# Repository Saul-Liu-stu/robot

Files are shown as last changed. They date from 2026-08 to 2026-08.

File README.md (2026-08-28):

# 轮腿混合四足机器人 robot_four_leg

基于 STM32H743 的轮腿混合机器人项目：四足步态 + 轮式移动双运动模式，含 IMU 姿态自稳、主动越障（原地抬腿/台阶辅助）与云台视觉，配套 Qt Android 蓝牙控制端 APP 与完整工程文档。

## 硬件平台

| 模块 | 型号 / 数量 | 接口 |
|---|---|---|
| 主控 | STM32H743ZIT6 (LQFP144) @ 480MHz | — |
| 舵机 | 12× 270°（4 腿 × 外展/大腿/小腿） | TIM2/3/4/12 PWM 50Hz |
| 轮电机 | 4× MG513 + TB6612 驱动（腿末端驱动轮） | TIM1/16/17 PWM |
| 编码器 | 4× GMR（与轮电机配套，轮速测量） | EXTI 双沿计数 |
| IMU | WT9011G4K | USART2 |
| 蓝牙 | HC-05（经典蓝牙 SPP） | USART3 |
| 云台 | 2× 180° 舵机 + 图传模块 | PWM |

完整引脚分配见 `docs/硬件/控制板引脚分配表.md`。

## 核心功能

- **轮腿双模**：平地轮式高效移动（最高约 1.7 m/s），崎岖地形对角步态（TROT）行走
- **足端轨迹规划 + 3D IK**：步态机以足端位置为控制目标，三关节解析逆解驱动 12 路舵机
- **姿态自稳**：IMU 反馈四腿 z 差动补偿，倾斜地面机身保持水平（Z 标定 + 开关控制）
- **主动越障**：原地抬腿（W，对角支撑+重心补偿）、台阶辅助抬升（N，双腿直抬+轮滚协同）
- **云台视觉**：二自由度云台 + 图传回传，APP 端颜色/运动检测
- **在线调参**：ASCII 蓝牙协议全指令文档化，运动参数在线可调

## 项目结构

```
robot_four_leg/
├── Core/           # STM32 用户层（main、命令协议解析、模式状态机）
├── Hardware/       # 行为/硬件层（步态 walk_gait、逆解 leg_ik、姿态控制 attitude_control、抬腿机动、轮式控制、云台、驱动）
├── Drivers/        # CMSIS + STM32H7xx HAL 库
├── QT_APP/         # Qt Android 蓝牙控制端 APP（UI/蓝牙传输/协议解析三层）
├── tools/          # Python 步态仿真与调参工具（IK 校验、行程余量、站起路径检查）
├── 3D结构文件/     # 机身与腿部 3D 打印模型（STL/STEP）
├── docs/           # 工程文档（协议、功能总览、测试清单、硬件资料、需求文档）
└── robot_four_leg.ioc   # CubeMX 工程配置
```

## 文档

- 蓝牙通信协议：`docs/协议/蓝牙通信协议.md`
- 功能总览：`docs/功能总览.md`
- 功能测试清单：`docs/功能测试清单.md`
- IMU 姿态自稳实现说明：`docs/IMU姿态控制方案.md`
- 需求文档：`docs/需求文档.md`
- 竞赛提交材料（开发日志、需求文档正式版等）：见材料包

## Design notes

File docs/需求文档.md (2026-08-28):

# 灵犬先锋轮腿机器人需求文档

| | |
|---|---|
| 项目名称 | 灵犬先锋——面向野外环境的探测与救援轮腿机器人 |
| 文档版本 | V1.0 |
| 编制日期 | 2026 年 8 月 10 日 |
| 编制人 | 项目团队 |

## 1. 项目背景

野外探测与救援任务中，废墟、山地、草地/土坡等复杂环境对移动平台提出苛刻要求：传统轮式平台通过性不足，纯四足平台平地效率低、控制复杂。本项目在电赛 QuadArm 原型基础上迭代，定位为**低成本的轮腿混合移动平台**——平地轮式高效移动，崎岖地形步态行走，并以 IMU 姿态自稳与主动越障能力支撑野外环境作业，为探测与救援类应用提供平台基础。

## 2. 目标与范围

- **目标**：以不超过 2000 元整机成本，实现轮腿双模移动、姿态自稳、主动越障与云台视觉四项核心能力，完成样机验证；
- **范围**：机器人本体（结构、硬件、固件）+ QT 蓝牙控制端（遥控 + 视觉检测）；
- **不包含**：自主导航、机械臂操作、远距通信（预留迭代空间）。

## 3. 功能需求

| 编号 | 需求描述 | 优先级 |
|---|---|---|
| FR-1 | 轮式移动：前进、后退、左转、右转、原地自转，四轮独立驱动 | 高 |
| FR-2 | 步态移动：对角步态（TROT），步长、步高、站高、站姿宽度参数化可调 | 高 |
| FR-3 | 站姿切换：高/低站姿切换与前倾修正 | 高 |
| FR-4 | 站起/趴下：站起机动（趴姿→站姿路径规划） | 中 |
| FR-5 | 姿态自稳：IMU 反馈四腿 z 差动补偿，倾斜地面机体保持水平（Z 标定 + 开关控制） | 高 |
| FR-6 | 主动越障：原地抬腿（对角支撑）；台阶辅助抬升（双腿同步直抬，与轮滚协同） | 高 |
| FR-7 | 云台与图传：二自由度云台指向控制，摄像头画面图传回传 | 中 |
| FR-8 | 上位机视觉：QT 端颜色检测与运动检测 | 中 |
| FR-9 | 遥控：按键遥控页（四向控制、速度档、站姿宽度调节），蓝牙串口协议全指令文档化 | 高 |
| FR-10 | 在线调参：全部运动参数支持在线修改，无需重新烧录 | 高 |

## 4. 性能需求

| 编号 | 指标 | 目标值 |
|---|---|---|
| PR-1 | 站高 | 210~280mm 在线可调（常用站姿 230mm） |
| PR-2 | 主动抬腿高度 | ≥50mm |
| PR-3 | 台阶通过 | 6~7cm |
| PR-4 | 坡面通过 | ≥10° |
| PR-5 | 轮式速度 | ≥1.5 m/s（轮毂直径 11cm，电机最高 300rpm） |
| PR-6 | 续航 | ≥1h（3S 2550mAh ×2） |
| PR-7 | 整机重量 | ≤1.5kg |
| PR-8 | 姿态自稳 | 死区 0.7°，稳态残差收敛（积分项消除） |
| PR-9 | 姿态反馈 | IMU 10Hz（俯仰/横滚） |
| PR-10 | 整机成本 | ≤2000 元 |

## 5. 可靠性需求

| 编号 | 需求描述 |
|---|---|
| RR-1 | IWDG 独立看门狗：异常卡死自动复位 |
| RR-2 | 舵机行程余量校验：所有姿态执行前校验行程可行性 |
| RR-3 | 姿态标定：各站姿 IMU 零偏分槽存储，上电可标定（Z 命令） |
| RR-4 | 抬腿高度受舵机行程约束保护（≤50mm） |

## 6. 设计约束

- 硬件平台：STM32H743 主控 + 12×270° 舵机 + 4×MG513 轮电机（TB6612）+ WT9011G4K IMU + 4×GMR 编码器 + 2×180° 云台舵机 + HC-05 蓝牙；
- 团队规模：3 人；开发周期：2026 年 8 月（约一个月集中开发）；
- 成本上限：2000 元；
- 通信：蓝牙串口（近距离遥控，远距通信为后续迭代方向）。

## 7. 验收对照

需求验收以《功能测试清单》逐项回归为准（姿态控制 / 步态 / 越障 / 遥控四类场景），全部核心场景通过即视为需求达成，遗留低优先级改进项记录于开发日志问题追踪表。

## 8. 需求变更记录

| 版本 | 日期 | 变更内容 |
|---|---|---|
| V1.0 | 2026 年 8 月 10 日 | 初版：功能迭代开始前需求梳理定稿 |

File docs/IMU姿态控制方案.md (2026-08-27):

# 四足轮腿机器人 IMU 姿态自稳实现说明

> 适用硬件：12 路舵机 + 4 路轮电机，IMU 为 WT9011G4K（UART 10Hz 主动上报）。
> 本文档描述**已实现的站立自稳**（attitude_control.c/h），非设计稿。

---

## 1. 功能概述

站立自稳：机器人在倾斜地面站立时，通过 IMU 姿态反馈，自动调节四腿足端高度（z 方向差动补偿），使机身保持水平。支持：

- 手动开关（`L:1`/`L:0` 绝对值命令，`L:` 裸命令切换）
- Z 标定（各姿态零偏分槽存储）
- 站立/原地抬腿（W 模式）自动激活
- 无倾斜轮式驱动（V 模式 1）自动跟随

## 2. 数据流

```
WT9011G4K (10Hz 上报)
   └─ imu.c 解析 pitch/roll
        └─ AttCtrl_CalibTick()   标定状态机 (5ms, 采样 2s 均值存零偏)
             └─ AttCtrl_LevelUpdate()   自稳解算 (50/100ms)
                  ├─ 低通滤波去抖
                  ├─ 软死区抑制微晃
                  ├─ 比例 + 积分 (消重心偏载常驻残差)
                  └─ 四腿 z 差动输出 (按站高动态限幅)
```

## 3. Z 标定与姿态分槽

不同站姿的 IMU 零偏不同，按姿态分槽存储（5 槽）：

| 槽 | 姿态 | 说明 |
|---|---|---|
| 0 | H（前后不反转，高） | 上电默认低趴并入此槽 |
| 1 | K（前反后不反，高） | |
| 2 | L（前反后不反，低） | |
| 3 | M（前不反后反，低） | |
| 4 | P（前不反后反，高） | |

- `Z` 命令：开始标定（放平地保持静止 2 秒）
- 标定完成后该姿态槽允许开启自稳（未标定姿态 `L:1` 返回错误）

## 4. 控制律

对相对零偏的俯仰/横滚角做处理：

```
flat_p = pitch - offset[pose]      (前倾为正)
flat_r = roll  - roffset[pose]     (右倾为正)

① 低通:  s_lp += alpha * (flat - s_lp)     alpha=0.25 @10Hz ≈ 0.35s 时间常数
② 软死区: |angle| < 0.7° → 0 (无阶跃软过渡)
③ 积分:  s_i += KI * dp, 钳位 pitch ±3° / roll ±6° (仅正常模式)
④ 输出:  pc = (dp + s_i) * rad * 190 (前后髋半距)
         rc = (dr + s_i) * rad * 90  (左右髋半宽)
         dz[FL]=pc-rc  dz[FR]=pc+rc  dz[RL]=-pc-rc  dz[RR]=-pc+rc
⑤ 限幅:  |dz| ≤ 304.6 - stand_h  (按站高动态算伸腿余量)
```

- **软死区**：±0.7° 内不响应（1° 偏粗、0.5° 过敏感，实测折中 0.7°）
- **积分项**：消除重心偏载的常驻残差（纯比例有稳态下垂），抗饱和钳位防发散
- **符号约定**：前倾→前腿伸/后腿收；右倾→右腿伸/左腿收

## 5. 激活条件（主循环判定）

| 场景 | 条件 |
|---|---|
| 站立 | `L:1` 已开 且 非坐/趴/起身/翻转 且 非双腿抬升 |
| 无倾斜驱动 | V 模式 1（LevelAuto 跟随） |
| 原地抬腿（W） | 无条件激活（TROT 且步长为 0），**快速模式** |

## 6. W 快速模式

原地抬腿时对角支撑，机身易翘板，采用快速调平：

| 参数 | 正常模式 | W 快速模式 |
|---|---|---|
| 调用周期 | 100ms | 50ms |
| 低通系数 | 0.25 | 0.50（约 0.1s 时间常数） |
| 死区 | 0.7° | 0.5° |
| 积分 | 启用（钳位 3°/6°） | 禁用（动态快，积分易发散） |

配合重心前移 15mm（W 命令），缓解对角支撑翘板。

## 7. 关键参数汇总

| 参数 | 值 | 说明 |
|---|---|---|
| LV_LPF | 0.25 | 正常低通（10Hz 调用 → 0.35s） |
| LV_LPF_FAST | 0.50 | W 快速低通（50ms 调用 → 0.1s） |
| LV_DEAD | 0.7° | 软死区（正常） |
| LV_DEAD_FAST | 0.5° | 软死区（W 快速） |
| LV_KI | 0.05/tick | 积分系数（约 2s 收敛） |
| LV_I_MAX_P / R | 3° / 6° | 积分抗饱和钳位 |
| LV_HALF_BL / BW | 190 / 90 mm | 前后髋半距 / 左右髋半宽 |
| LV_Z_ROOM_BASE | 304.6mm | 伸腿上限基准（动态限幅用） |

## 8. 已验证效果

- 平地站立：水平保持良好，微晃抑制，重心偏载残差由积分项收敛
- 户外实测：草地/土坡约 10° 坡度站立，机身保持水平
- W 原地抬腿：快速调平 + 重心偏移，翘板明显缓解
- 遥控场景：`L:1/L:0` 绝对值开关保证 APP 与固件状态同步

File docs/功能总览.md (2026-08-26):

# 四足轮腿机器人 — 功能总览 v1.0

> 本文件是机器人**当前所有功能的总索引**，后续新增/修改功能直接在本文件更新，并同步在文末"更新日志"追加一条。
> 命令细节以 [协议/蓝牙通信协议.md](协议/蓝牙通信协议.md)（v6.4）为准；标定与余量以 [硬件/3DIK标定数据.md](硬件/3DIK标定数据.md) 为准。

---

## 一、硬件配置

| 模块 | 配置 |
|---|---|
| 主控 | STM32H743ZITx @480MHz |
| 舵机 | 12×270° 数字舵机（三块舵机板），50Hz PWM，5ms 批量更新 |
| 轮式电机 | 4×MG513 + TB6612×2，PWM 驱动（占空比 0~100%）；轮径 **108mm**（2026-08-20 更换，旧 65mm） |
| 编码器 | 4×GMR 编码器，EXTI 双沿计数（满速输出轴 ≈360 RPM，50% 占空比 ≈180 RPM） |
| IMU | WT9011G4K 九轴，USART2 115200bps，上电时序双保险（ErrorCallback 自愈 + 看门狗） |
| 蓝牙 | HC-05 SPP 115200bps，TX 走 DMA（带 D-Cache 刷新） |

---

## 二、功能分类总表

| 类别 | 功能 | 命令 |
|---|---|---|
| 姿态 | 狗高站姿 280mm | `G` / `H` |
| 姿态 | **正常膝低站姿**（200~280 缺省 230，站得越低自稳补偿坡度越大） | `H:高度` |
| 姿态 | 前顶高站姿（前腿反折膝）280mm | `K` |
| 姿态 | 后顶高站姿（后腿反折膝）280mm | `P` |
| 姿态 | 前顶低趴 191mm（四轮驱动，大腿≈水平+小腿垂直视觉姿态） | `L` |
| 姿态 | 后顶低趴 240mm（四轮驱动） | `M` |
| 姿态 | **收纳（贴地趴）** 72mm 慢速缓降（断电放置） | `C` |
| 姿态 | **规划式站起**（顶升+收腿到前顶低趴 191，免翻膝约 3.5s） | `U` |
| 姿态 | **坐姿**（前腿竖直+后腿反折深蹲，狗坐造型） | `O` |
| 姿态 | **单腿抬腿**（抬 50mm×前伸 80mm / 慢慢放下，仅空中腿互斥，每腿前伸记忆 80mm 可四腿依次迈出，支撑腿重心转移 15mm 防倾覆，自稳保持，行进可用） | `N:腿:动作` |
| 姿态 | **上台阶双腿抬**（N:4/N:5：前/后双腿 50mm 直抬，同时抬起，按住抬/松开放，台阶阶段自稳让位，轮子为主腿为辅） | `N:4:1` / `N:5:1` |
| 云台 | **云台舵机**（180° ×2：pan 0~180 正前=90 / tilt 75~180 正前=120，上电自动回正前方） | `G:水平:俯仰` |
| 姿态 | 翻膝机动（姿态切换自动执行，约 3s） | 自动，回显 `FLIP` |
| 步态 | 连续 Trot（步幅 60/抬腿 25/1.2s） | `T` |
| 步态 | 越障抬腿（高站姿对角**原地**抬腿 50mm，前进由 V 无倾斜轮盘控制） | `W` + `V:..:1` |
| 步态 | 转圈动作（顺/逆时针） | `E` / `E:0` |
| 步态 | 单步调试（相位 0/90/180/270） | `A` |
| 轮式 | 一键前进/后退/停（30%） | `R` / `B` / `S` |
| 轮式 | 电机单控 | `M0:50:1` |
| 轮式 | **摇杆遥控**（差速+斜坡+倾斜平衡；模式1=无倾斜补偿+高站姿+自稳保持） | `V:速度:转向[:模式]` |
| 轮式 | **方向按键**（固定倾斜全程保持，S 才回平；模式1=无倾斜+转向 20/30 小差速+自稳跟 L:1；速度档 U:1/U:0 加减步进5，回 SPD 实时显示） | `D:方向[:速度[:模式]]` + `U:1`/`U:0` |
| 自稳 | **站立自稳**（H/K 高站姿下四腿 z 差动补偿，不平地面身体保持水平） | `Z` 标定 + `L:1` / `L:0` |
| 传感 | IMU 姿态上报（10Hz，520 帧） | `I` 开关 |
| 传感 | 编码器转速上报（10Hz，520 帧） | `J` 开关 |
| 修正 | 前倾修正（足端前后移） | `X:毫米` |
| 校准 | 舵机校准（重装舵机臂用） | `1~12` / `Y` / `N` |

---

## 三、姿态系统（五姿态 + 翻膝）

### 3.1 五姿态

| 姿态 | 站高 | 前腿膝 | 后腿膝 | 用途 |
|---|---|---|---|---|
| G/H 狗高 | 280 | 正常 | 正常 | 行走、越障 |
| K 前顶高 | 280 | 反折 | 正常 | 展示/特殊 |
| P 后顶高 | 280 | 正常 | 反折 | 展示/特殊 |
| L 前顶低趴 | 220 | 反折 | 正常 | 四轮驱动 |
| M 后顶低趴 | 220 | 正常 | 反折 | 四轮驱动（重心集中） |

- 低趴姿态足端展开（L 四足 ±129.5 对称、M 前 +45/后 -120），膝高(几何) L 180mm、M 134/112mm，实际离地再 +54mm（108mm 轮径），支撑中心在身下
- 上电默认：狗姿态 280mm（`G` 即可站立）

### 3.2 翻膝机动

- 前后腿膝分支（正常/反折）在"直腿点"（足端伸到 L1+L2）连续
- 切换需要翻膝的组合时自动执行：足端伸到直腿点 → 翻转分支 → 收回，约 3s
- K↔L、M↔P 同分支直接升降，无翻膝
- 全程膝离地 ≥110mm，回显 `FLIP`

---

## 四、步态系统

| 功能 | 说明 |
|---|---|
| `T` 纯 Trot | 对角抬腿行走 + **四轮 10% 助走**，步幅 60mm / 抬腿 25mm / 周期 1.2s / 支撑比 0.6；退出行走（G 等）自动停轮 |
| `T:-1` 倒走 | 负步幅反向 trot + 四轮 10% 反向助走 |
| `W` 越障 | 高站姿 280 + 对角**原地**抬腿 50mm（足端不前后移、不动轮；70mm 时后腿舵机贴 270° 极限抬不动）；**自稳自动跟随**（支撑腿 z 补偿，防对角支撑翘板，需 Z 标定）；前进由 `V:速度:转向:1` 无倾斜轮盘控制，边抬腿边走，可跨 ~30mm 障碍（108mm 大轮） |
| `E`/`E:0` 转圈 | trot + 15mm 重心横移，原地顺/逆时针旋转 |
| `A` 单步 | 相位冻结，每次 +1/4 周期，调试用 |

---

## 五、轮式系统

### 5.1 一键与单控

- `R` 四轮 30% 前进 / `B` 后退 / `S` 急停
- `M电机号:速度[:方向]` 单电机控制（2026-08-20 重接线后四路同极性，无方向补偿）

### 5.2 摇杆遥控（APP 第四页）

```
命令: V:速度:转向[:模式]   范围 −50~+50, V 值 = 占空比% (1:1)
      速度负=后退, 转向负=左转/正=右转
差速: 左轮 = 速度+转向, 右轮 = 速度−转向 (限幅±100)
斜坡: 0.5s 渐变到目标占空比 (起步不猛)
回中: V:0:0 → 渐停 + 回平 (急停用 S)
回显: 无 (高频流, APP 不要等应答)

模式1 (第二套轮盘, V:sp:st:1):
- 无倾斜补偿: 起步不低头/不压弯
- 反折膝自动翻回 H (回 FLIP), 翻完前驱动忽略; 正常膝按当前站高行驶 (H:230 蹲低爬陡坡)
- 自稳自动跟随: 平台水平由 IMU 自稳层保持 (需先 Z 标定 H, 无需 L:1)
```

### 5.3 倾斜平衡（V 自动附带）

| 场景 | 动作 | 幅度 |
|---|---|---|
| 起步加速 | 平台低头（前腿 z 缩短/后腿 z 伸长） | ∝(命令−实际占空比)，上限 15mm ≈4.5° |
| 刹车减速 | 平台抬头 | 反向 |
| 左/右转 | 向弯内压弯（左右 z 差动） | ∝转向量，上限 10mm ≈2.7° |
| 到速 | 编码器平台期判定（300ms 窗口增量 <2 RPM）→ 回平 | 0.3s 渐变 |
| 兜底 | 斜坡完成自动回平（编码器无信号也可用） | — |

---

## 六、站立自稳（H/K 高站姿）

> 2026-08-23 坡度自适应层已删除（未实测、与自稳职责重叠），Z 改为纯自稳标定。

- `Z` 平地标定（存 pitch/roll 零偏，每姿态分存）→ `L:1` 开启 / `L:0` 关闭
- 仅 **H（狗高）**、**K（前顶高）** 280mm 生效；P 后顶站不启用（RR 大腿余量仅 7°）
- 原理：身体往哪边倾哪边腿伸长（10Hz 低通约 0.35s），单腿 z 补偿上限**按站高动态算**（`304.6 − 站高`）
- **死区 ±0.5°**（2026-08-26 精度升级）+ **积分项**消重心偏载常驻残差（约 2s 收敛，抗饱和）
- 补偿坡度能力（pitch，直腿点几何极限）：280 站高 ≈7.5° / 230 ≈23° / 220 ≈26.5° / 210 ≈30°；超出钳位、保留剩余倾斜
- 爬陡坡：`H:230` 边开边蹲 → `V:..:1` 上坡保持水平 → 回平地 `H` 站起
- 仅站立静止或 **V 模式1 无倾斜驱动中**叠加；行走/站起/翻膝/收纳/坐姿中自动清零

## 七、传感数据上报

| 流 | 开关 | 频率 | 帧格式 |
|----|---|---|---|
| IMU 角度 | `I` | 10Hz | `R,x,P,y,Y,z,520`（×10 定点，0.1°） |
| 编码器转速 | `J` | 10Hz | `E,e0,e1,e2,e3,520`（RPM） |

- 帧尾 520 校验；上报与命令回显交错，上位机按前缀分发
- IMU 符号：前倾 P 正、后倾 P 负（上坡 = P 负）

---

## 八、关键参数（当前值）

| 参数 | 值 | 位置 |
|---|-----|---|
| 腿长 L1/L2/髋偏置 | 130/180/10 mm | leg_ik.h |
| 机身 BL/BW | 380/180 mm | leg_ik.h |
| 站高 低/高 | 220/280 mm | walk_gait.h |
| 前倾修正 X | 15 mm | walk_gait.c |
| 轮径 | 108 mm（旧 65mm 已更换） | 硬件 |
| 车速 | 50% 占空比 ≈180 RPM ≈ **1.0 m/s**（108mm 轮；旧轮 0.6） | 换算 |
| 转圈横移量 | 15 mm（定死） | walk_gait.c |
| 越障抬腿 | 50 mm（70 时后腿舵机贴 270° 极限） | main.c |
| 倾斜上限 | 低头 15mm / 压弯 10mm | drive_ctrl.c |
| 转速换算 | V 值 = 占空比%，满速 50 ≈180 RPM | drive_ctrl.c |

---

## 九、常用操作流程

```
上电 → READY
  ├─ G → T         纯行走
  ├─ G → W         越障
  ├─ G → E/E:0     转圈
  ├─ L/M → R/B/S   四轮驱动（低趴）
  ├─ V:30:0        摇杆遥控（倾斜自动）
  ├─ I / J         传感数据显示
  └─ X:毫米        前倾修正
```

---

## 十、已知限制与待办

- [ ] 低趴 240 时勿发 T（会钳位）；行走前先 `G`/`H`
- [ ] 横移走 F 已暂停（代码保留）
- [ ] 镇定层（站立自稳/行走镇定）暂缓
- [ ] 编码器功能仅用于显示与倾斜平台期判定
- [ ] 舵机校准命令当前启用，正式版改回 `#if 0`

---

## 更新日志

| 日期 | 内容 |
|---|---|
| 2026-08-19 | v1.0 初版：五姿态、步态、轮式+摇杆遥控+倾斜平衡、坡度、传感上报、校准、修正 |
| 2026-08-19 | 新增 D 方向按键（固定倾斜全程保持、S 才回平）；修正压弯方向 bug（左转=左边低）；V 映射改 1:1（V 值=占空比%） |
| 2026-08-19 | D 按键默认速度 30；弧线调紧（转向分量 spd/2→3spd/5）；倾斜加大（低头/抬头 10mm、压弯 10mm） |
| 2026-08-19 | D 按键切换动作改为"先回平再倾斜"两段式（约 0.2s+0.2s），不再直接横摆 |
| 2026-08-19 | 新增 C 收纳命令（150mm 最深低趴，断电放置安全落地；G 一键站起） |
| 2026-08-19 | C 升级为 72mm 贴地趴（慢速缓降 2~3s，断电落差仅 ~32mm）；新增 U 规划式站起（阶段A收腿+顶升 3.5s + 阶段B翻膝升 280） |
| 2026-08-19 | U 上电后直接可用（g_booted 门控，13 处命令清除点）；C 收纳保持单段贴地趴（收小腿方案因断电落差权衡撤销） |
| 2026-08-20 | 更换轮毂 65→108mm（半径+21.5mm）：膝高几何值不变、实际离地 +21.5mm；C 收纳断电落差 32→~53mm（着地轮子锚定车身）；同占空比车速约 +67%（50% ≈1.0 m/s）；越障上限提高 |
| 2026-08-20 | 低趴高度 220→240：108mm 大轮负载下 FR 站起堵转，抬高 20mm 缩短升站行程、足端内收降低力矩（余量 20°/12°→32°/24°） |
| 2026-08-20 | 新增单腿足端零位修正 foot_x_corr[4]：RR 落地点偏前（小腿零位偏差，实测），RR 补 −20mm（−30 实测偏后回退）；后续机械重标 RR 零位后移除 |
| 2026-08-20 | T 前进行走新增四轮 10% 助走（E 转圈不助走）；退出行走模式（G 等姿态命令）自动停轮，急停用 S |
| 2026-08-21 | L 前顶低趴改视觉姿态（191mm、四足 ±129.5 对称、大腿≈水平+小腿垂直）；U 站起改单段（顶升+收腿直接站到 L，免翻膝约 3.5s） |
| 2026-08-21 | 新增坐姿 O（前腿竖直伸直+后腿反折深蹲，狗坐造型，最小余量 13.3°）+ 倒着走 T:-1（负步幅+轮反向助走） |
| 2026-08-22 | 新增云台双舵机（TIM8 CH3/CH4：PC8/PC9，50Hz），蓝牙 G:水平:俯仰 控制，上电默认 135/135 |
| 2026-08-23 | 新增站立自稳（H/K 高站姿，L:1/L:0 开关，Z 标定存 pitch/roll 零偏，四腿 z 差动 ±25mm 限幅）；Z 标定完成回显改 CAL:OK |
| 2026-08-23 | 新增 IWDG 看门狗（LSI 32kHz/32 分频，reload 2047 ≈2.05s 超时，主循环喂狗；主循环卡死/Error_Handler 自动复位，蓝牙失效免断电；调试暂停时冻结） |
| 2026-08-23 | 自稳加 ±1° 死区（太敏感反馈）；V 命令新增模式1（无倾斜补偿+高站姿+自稳自动跟随，第二套轮盘），自稳激活条件扩展（L:1 或 模式1） |
| 2026-08-23 | 删除坡度自适应层（未实测、与自稳职责重叠）：Z 改为纯自稳标定，Q 调参命令移除，g_slope_shift/g_wheel_on/s_parse_float 清理 |
| 2026-08-23 | 新增 H:高度 正常膝低站姿（200~280 缺省 230，翻膝后降高 post=8）；自稳补偿上限动态化（304.6−站高，280≈25mm 行为不变，230 可补偿 23° 坡） |
| 2026-08-23 | 云台俯仰自稳试做后删除（出问题：实测不稳，回退纯轮盘控制；ARR 保持 199） |
| 2026-08-24 | W 越障改回原地抬腿（step_len 50→0，去掉四轮 30% 自动前进）；前进由 V 无倾斜轮盘配合控制 |
| 2026-08-24 | W 抬腿 70→50mm（实测 70mm 时后腿舵机贴 270° 极限抬不动）；W 加自稳跟随（支撑腿 z 补偿，防对角支撑翘板——无自稳时重心偏一侧只抬得起一条腿） |
| 2026-08-24 | W 自稳改快速档（50ms 快拍 + 低通 0.1s + 死区 0.5° + 跟随速率 0.4）：实测矫正太慢追不上翘板；站立模式参数不变 |
| 2026-08-24 | W 加重心横移补偿（W:毫米 在线调，默认 15mm 左移）：实测机身右侧偏重（右倾+右转），对角支撑时绕支撑线倾倒静态不可控，重心必须摆到对角线上 |
| 2026-08-25 | 新增按键驾驶新页 D 模式1（D:方向:速度:1：前进/后退 30 基准，转向 25±5 小差速，无倾斜补偿，自稳跟全局 L:1）；拆分 NoTilt 与自稳跟随（LevelAuto）两个标志，L:0 总开关清两者 |
| 2026-08-25 | 新增单腿抬腿（N:腿:动作：50mm×80mm，抬 0.8s/放 1.2s，互斥单腿，自稳保持+行进可用，前伸位保持至姿态命令） |
| 2026-08-25 | 修复外展 y 通道符号反转（实测右后腿内收发现）：W 重心补偿与 N 重心转移的命令符号翻转——此前 +15mm 实际把身体推向重的一侧，越调越糟 |
| 2026-08-25 | 新增上台阶双腿抬（N:4/N:5：50mm 直抬 + 交错 0.3s，按住抬/松开放，台阶阶段自稳/倾斜让位，轮子为主腿为辅） |
| 2026-08-25 | 按键页新增速度档加减（U:1/U:0 步进5 范围10~50，回 SPD 实时显示，驾驶中立即生效）；D 缺省速度改读速度档；上台阶双腿改同时抬 |
| 2026-08-26 | 修复自稳失效 bug（抬腿哨兵值 0xFF 参与大小比较：站立空闲时自稳/倾斜平衡被误关——三处门槛改显式排除双腿模式）；自稳精度升级（死区 1→0.5°、低通 0.6→0.35s、新增积分项消重心偏载残差） |
| 2026-08-26 | 修复遥控时自稳丢失：W 自稳改无条件（此前经典轮盘 V 清跟随标志会把 W 自稳杀掉）；L:1/L:0 改绝对值语义（防 APP 状态错位，裸 L: 仍切换）；死区折中 0.7° |
| 2026-08-20 | W 越障单腿依次抬方案实测效果差，改回对角交替抬 + 摆动相前伸 50mm（抬起→前伸→落下→回收，支撑相推身体前进），轮子持续前推 |
| 2026-08-20 | 升站慢速平滑：站高上升方向（低趴→高姿态）平滑速率 0.12→0.04（约 1.5s 渐变），大轮负载下舵机跟得上；下降与翻膝保持原速 |

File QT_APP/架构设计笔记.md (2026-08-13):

# Qt 蓝牙上位机架构设计笔记

> 适用场景：通过经典蓝牙 SPP 与 MCU 通信、需要处理多版本协议的 Qt Android App

---

## 1. 分层架构：每层只做一件事

```
┌─────────────────────────────────────┐
│  mainwindow      UI 层              │  只管布局 + 信号连接
│  servowidget / pidwidget            │  只管展示 + 用户交互
├─────────────────────────────────────┤
│  bluetoothclient  蓝牙传输层         │  只管连接 + 收字节 + 发字节
├─────────────────────────────────────┤
│  protocol_core    协议解析层         │  纯函数，无状态，无 Qt 依赖
└─────────────────────────────────────┘
```

**核心原则：下层不知道上层存在。** `protocol_core` 不知道谁在调用它，`bluetoothclient` 不知道 UI 长什么样。

---

## 2. 多协议共存：加新不加删，前缀分流

三种协议写三个独立解析函数，互不覆盖：

```cpp
// 协议层 — 每阶段一个函数，互不干扰
ServoResponse  parseServoLine(line);      // 阶段一：舵机校准
PidMessage     parsePidLine(line);        // 阶段二：PID 调参
int            parseTelemetryLine(...);   // 阶段三：步态+IMU（未启用）
```

**传输层按前缀排队分发，不匹配就跳过**：

```cpp
void processBuffer() {
    // 阶段一：舵机 — 首字符 "S" 或 "O"
    ServoResponse sr = parseServoLine(line);
    if (sr.event != None) { emit servoXxx(sr); return; }

    // 阶段二：PID — 数字/负号/字母
    PidMessage pm = parsePidLine(line);
    if (pm.type != PidNone) { emit pidXxx(pm); return; }

    // 阶段三：IMU — 首字符 "R" 或 "A"
    TelemetryData td;
    if (parseTelemetryLine(line, &td)) { emit telemetryReceived(td); return; }
}
```

**为什么不会串：** 三种协议的首字符天然互斥

| 协议 | 首字符 | 示例 |
|---|---|---|
| 舵机 | `S` `O` | `Servo Calib Ready` `OK:135` |
| PID | 数字 `-` `P` `K` `T` `G` `S` | `58,60,45` `Kp=5` `GO` |
| IMU | `R` `A` | `R:1.5 P:-0.3 Y:45.2` `A:12345/...` |

---

## 3. UI 页面切换：QStackedWidget + 握手信号

```cpp
// 构造时预建所有页面，不删不重建
m_stack = new QStackedWidget;
m_stack->addWidget(m_servoWidget);  // index 0
m_stack->addWidget(m_pidWidget);    // index 1
m_stack->setCurrentIndex(1);        // 默认显示 PID

// 连接后根据握手自动切页
connect(m_bt, &BluetoothClient::pidReady,   this, [this]() { m_stack->setCurrentIndex(1); });
connect(m_bt, &BluetoothClient::servoReady, this, [this]() { m_stack->setCurrentIndex(0); });
```

**好处：** 无论连什么固件，自动识别，无需用户手动切模式。

---

## 4. 命令发送：让 UI 只关心语义

PID 面板只发信号 `commandRequested("P+")`，不关心底层怎么编码：

```cpp
// pidwidget.cpp — UI 层：只管用户意图
connect(btn, &QPushButton::clicked, this, [this]() {
    emit commandRequested("P+");    // 纯语义
});

// mainwindow.cpp — 桥接层：路由到传输层
connect(m_pidWidget, &PidWidget::commandRequested, this, [this](const QString &c) {
    m_bt->sendPidCmd(c);   // "P+" → "P+\r\n" → write()
});

// protocol_core.cpp — 协议层：负责编码
QByteArray buildPidCmd(const QString &cmd) {
    return cmd.toUtf8() + "\r\n";   // "P+" → "P+\r\n"
}
```

三层各司其职：
- `pidwidget` 不知道有 `\r\n`
- `mainwindow` 不知道编码细节
- `protocol_core` 不知道谁在调用

---

## 5. 文件保存：QFileDialog 自动跨平台

```cpp
void onExportCsv() {
    // 一行代码，Android 调 SAF，Windows 弹原生对话框
    QString path = QFileDialog::getSaveFileName(
        this,
        "导出 CSV",           // 标题
        "servo_calib.csv",    // 默认名
        "CSV (*.csv)"         // 类型过滤
    );
    if (path.isEmpty()) return;  // 用户取消

    // 拿到路径后就是标准 Qt 写文件
    QFile f(path);
    if (f.open(QIODevice::WriteOnly | QIODevice::Text)) {
        QTextStream out(&f);
        out << "Servo,Angle\n";
        for (int i = 0; i < 12; i++)
            out << "S" << (i+1) << "," << m_savedAngles[i] << "\n";
        f.close();
    }
}
```

**思路：** Qt 帮我处理平台差异，我只管读写字节能打开的文件路径。

---

## 6. Android 蓝牙 JNI：照抄能跑的模式

核心三板斧，来自已验证可运行的参考工程：

```cpp
// ① JNI 引用用 void* 存，QJniObject 临时构造
void *m_javaSocket = nullptr;     // BluetoothSocket 全局引用
void *m_outputStream = nullptr;   // OutputStream 全局引用

// ② 连接：先反射 channel=1，失败回退 SPP UUID
bool connectRfcomm(const QString &address) {
    QJniObject adapter = QJniObject::callStaticObjectMethod(
        "android/bluetooth/BluetoothAdapter", "getDefaultAdapter",
        "()Landroid/bluetooth/BluetoothAdapter;");
    // ... 获取 Device → 反射 createRfcommSocket(1) → connect() →
    // 回退 createRfcommSocketToServiceRecord(SPP_UUID)
}

// ③ 后台线程读流
class RfcommReader : public QThread {
    void *m_inputStream;    // void* 存全局引用
    void run() override {
        QJniObject is(static_cast<jobject>(m_inputStream));  // 临时构造
        while (m_running) {
            jint n = is.callMethod<jint>("read", "([B)I", jbuf);
            // ... emit dataReceived(chunk) → 主线程处理
        }
    }
};
```

**为什么用 void\* 而不是 QJniObject 成员：** `QJniObject` 析构时会自动释放本地引用，但读写线程需要的是全局引用。用 `void*` 显式管理全局引用的生命周期，不容易出错。

---

## 7. CMakeLists.txt：极简模板

```cmake
cmake_minimum_required(VERSION 3.16)
project(MyApp VERSION 1.0 LANGUAGES CXX)
set(CMAKE_CXX_STANDARD 17)
set(CMAKE_CXX_STANDARD_REQUIRED ON)
set(CMAKE_AUTOMOC ON)                    # 关键：自动处理 Q_OBJECT

find_package(Qt6 REQUIRED COMPONENTS Core Widgets Bluetooth)

qt_add_executable(MyApp
    main.cpp
    protocol_core.h    protocol_core.cpp
    bluetoothclient.h  bluetoothclient.cpp
    mainwindow.h       mainwindow.cpp
)

target_link_libraries(MyApp PRIVATE Qt6::Core Qt6::Widgets Qt6::Bluetooth)

if(ANDROID)
    set_target_properties(MyApp PROPERTIES
        QT_ANDROID_MIN_SDK_VERSION 26
        QT_ANDROID_TARGET_SDK_VERSION 35
    )
    target_link_libraries(MyApp PRIVATE log)  # Android 必须
endif()
```

**要点：**
- `CMAKE_AUTOMOC ON` 替代 `qt_standard_project_setup()`，避免 Android 兼容问题
- `log` 库必须链接，否则 Android 原生日志调用崩溃
- 不要手写 `android/` 目录，让 Qt 自动生成 AndroidManifest

---

## 8. 权限请求：放在传输层，和扫描绑定

```cpp
// bluetoothclient.cpp
void BluetoothClient::startScan() {
    requestPermAndScan();   // 先请求权限，拿到后再 doStartScan()
}

void requestPermAndScan() {
    QBluetoothPermission bp;
    if (qApp->checkPermission(bp) == Qt::PermissionStatus::Undetermined) {
        qApp->requestPermission(bp, [this, lp]() {
            // 蓝牙权限拿到后，再查位置权限，串行请求
            if (qApp->checkPermission(lp) == Qt::PermissionStatus::Undetermined)
                qApp->requestPermission(lp, [this]() { doStartScan(); });
            else doStartScan();
        });
        return;
    }
    doStartScan();
}
```

**为什么不在 `main()` 里请求：** Android 权限弹窗是异步的，`main()` 里请求时 UI 还没起来，回调可能丢失。

**为什么不手写 `AndroidManifest.xml`：** Qt 自动生成的清单会根据 `find_package(Qt6 Bluetooth)` 和 target 属性自动加好权限，手写容易和自动生成冲突导致资源合并失败。

---

## 总结：好改的代码长什么样

| 场景 | 做法 |
|---|---|
| 协议迭代 | 新解析函数 + processBuffer 前面插一行 |
| UI 换版 | 新 Widget + QStackedWidget 加一页 |
| 加新命令 | UI 层发新信号 + 协议层加新函数 + 传输层加 sendXxx() |
| 跨平台 | Qt 抽象好的 API（QFileDialog、QBluetoothPermission）直接用 |
| 第三方依赖 | 尽可能少。这个工程零外部库 |

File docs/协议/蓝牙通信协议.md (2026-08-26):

# 蓝牙通信协议 v6.20

> HC-05 SPP | 115200 bps | TX: DMA(带缓存刷新) | RX: 中断

---

## 传输层

| 参数 | 值 |
|---|-----|
| 模块 | HC-05 经典蓝牙 SPP |
| 波特率 | 115200 bps |
| 数据/校验/停止 | 8 / None / 1 |
| 引脚 | PB10(TX) / PB11(RX) |
| Android UUID | `00001101-0000-1000-8000-00805F9B34FB` |

---

## 全部命令速查

### 步态控制（3D IK + walk_gait 版）

| 命令 | 效果 | 应答 |
|---|---|---|
| `G` | **站立 = 狗高站姿 280** — 前后正常膝，站高 280mm（反折膝先翻膝再升），5ms 平滑循环渐进 | `STAND...` → `OK:STAND` |
| `G:水平:俯仰` | **云台舵机** — 水平 pan 0~180（90 正前）/ 俯仰 tilt 75~180（120 正前，俯仰可省略），上电自动回正前方 | `GM:水平,俯仰` |
| `H` | **狗姿态高站姿** — 前后腿正常膝，站高 280mm（行走/越障用） | `HIGH` |
| `H:高度` | **正常膝低站姿** — 指定站高 200~280（缺省 230），站得越低自稳可补偿坡度越大（爬陡坡用，如 `H:230`） | `HIGH:230` |
| `K` | **前顶高站姿** — 前腿反折膝 + 后腿正常，站高 280mm | `KNEE` |
| `L` | **低趴（前顶版）** — K 姿态趴到 191mm（四足 ±129.5 对称，大腿≈水平+小腿垂直的视觉姿态） | `LOW` |
| `M` | **低趴（后顶版）** — 前腿狗腿正常 + 后腿反折膝往前突，趴到 240mm，重心集中 | `REAR` |
| `P` | **后顶高站姿** — 前腿狗腿正常 + 后腿反折膝往前突，站高 280mm（M 的高姿态版） | `REARH` |
| `C` | **收纳（贴地趴）** — 72mm 慢速缓降趴平（四腿伸直外展 ±297，肚皮离地 ~53mm），断电放置用 | `PARK` |
| `U` | **规划式站起** — 从贴地趴单段起身：顶升+收腿到**前顶低趴 191mm**（与趴姿同膝分支，免翻膝，约 3.5s），之后 G/K 可再升 | `RISE` → `LOW` / `NOT PARK` |
| `O` | **坐姿** — 前腿竖直伸直 + 后腿反折深蹲（狗坐造型，车身自然抬头约 10°；后腿正常膝时自动翻膝） | `SIT` |
| `X:20` | **前倾修正** — 足端前移 20mm（身体后坐），站立/行走同时生效，`X:-10` 反向 | `XSH:20` |
| `I` | **IMU 上报开关** — 10Hz 角度流（`R,x,P,y,Y,z,520` 帧），再按关闭 | `IMU:ON` / `IMU:OFF` |
| `V:sp:st[:模式]` | **摇杆驱动** — 速度/转向 −50~+50（速度负=后退，转向负=左/正=右），差速+斜坡+倾斜平衡，**高频流不回显**；模式 1=**无倾斜补偿**+高站姿280+自稳保持（第二套轮盘） | 无（模式1反折膝时先回 `FLIP`） |
| `D:dir[:spd[:模式]]` | **方向按键** — 0=前进 1=后退 2=左前/左转 3=右前/右转，spd 10~50 缺省=按键页速度档（`U:1`/`U:0` 调）；模式 0/缺省=经典固定倾斜全程保持，`S` 回平；**模式 1=新按键页**（无倾斜补偿，转向 20/30 小差速，自稳跟全局 `L:1` 走） | `DRV:0:30` |
| `U:1` / `U:0` | **按键页速度加减** — 步进 5、范围 10~50；按键驾驶中立即生效；回 `SPD:数值`（APP 实时显示） | `SPD:35` |
| `Y:毫米` | **站姿宽度偏移** — 每足足端向外偏移（±40，默认 0），支撑面加宽抗侧倾；驾驶/站立/抬腿全程生效；裸 `Y` 仍是校准确认 | `WID:15` |
| `J` | **编码器转速上报开关** — 10Hz 转速流（`E,e0,e1,e2,e3,520` 帧），再按关闭 | `J:ON` / `J:OFF` |
| `Z` | **自稳标定** — 当前姿态采样 2s 存 pitch/roll 零偏（每姿态单独存，放平地标定；重复按可重标覆盖） | `CALIB...` → `CAL:OK` |
| `L:1` / `L:0` | **站立自稳开关**（**绝对值**：`L:1` 强制开、`L:0` 强制总关+清跟随残留，可重复发不翻转——APP 状态同步用；裸 `L:` 才切换）；先 `Z` 标定当前姿态；单独 `L` 仍是低趴姿态 | `LV:ON` / `LV:OFF` / `LV:NOCAL` |
| `A` | **单步调试** — 首次进相位0，之后每次 +1/4 周期，平滑过渡后停住 | `PH:0` / `PH:90` / `PH:180` / `PH:270` |
| `T` | **连续 Trot** — 纯 trot（无重心横移）+ **四轮 10% 助走**（前进更流畅），相位从0开始；`G`/姿态命令退出时自动停轮 | `TROT` |
| `T:-1` | **倒着走** — 负步幅反向 trot + 四轮 10% 反向助走 | `TROTB` |
| `E` | **转圈动作** — trot + 重心横移（定死 15mm）；`E`/`E:1` 顺时针，`E:0` 逆时针 | `SWAY:1` / `SWAY:-1` |
| `W[:毫米]` | **越障抬腿** — 高站姿 280mm + 对角交替**原地**抬腿 50mm（不动轮；**自稳自动跟随**防翘板，需先 Z 标定；`W:毫米` 调重心横移补偿 ±40 默认 15；前进由 `V:速度:转向:1` 无倾斜轮盘控制；任何腿反折膝都会先翻膝回正常） | `CLIMB` → `FLIP` |
| `N:腿:动作` | **抬腿** — 腿 0=FL 1=FR 2=RL 3=RR（单腿：50mm 高 × 80mm 前伸，前伸记忆上限 80mm）；**腿 4=前双腿、5=后双腿**（上台阶：50mm 直抬、交错 0.3s、按住发1/松开发0）；动作 1=抬起 0=慢慢放下；仅空中腿互斥；自稳单腿保持/双腿让位；行进中可用；裸 `N` 仍是校准退出 | `LG:腿,1` / `LG:腿,0` / `LG:BUSY` / `LG:NO` |

### 电机控制

| 命令 | 效果 | 应答 |
|---|---|---|
| `R` | **一键滚动** — 四电机 30% 正转 | `ROLL` |
| `B` | **一键后退** — 四电机 30% 反转 | `BACK` |
| `S` | **一键停** — 四电机全停 | `STOP` |
| `M0:50:1` | 电机A 50%占空比 正转 | `MA:50:1` |
| `M1:30:0` | 电机B 30% 反转 | `MB:30:0` |
| `M2:100` | 电机C 100% 正转（方向缺省=正转） | `MC:100:1` |
| `M0:0` | 电机A 停止 | `MA:0:1` |

- 电机号 `0~3` = A/B/C/D
- 速度 `0~100`（0 = 停止）
- 方向 `1`=正转, `0`=反转, 可省略
- A/B 电机的方向已在驱动层纠正（接线相反），命令语义统一

### 舵机校准（已启用，重装舵机臂后标定用；标定完可改回 `#if 0`）

舵机编号映射：

| 编号 | 关节 |
|---|---|
| 1~4 | 外展（FL / FR / RL / RR） |
| 5~8 | 大腿（FL / FR / RL / RR） |
| 9~12 | 小腿（FL / FR / RL / RR） |

| 命令 | 效果 | 应答 |
|---|---|---|
| `1`~`12` | 切换校准舵机号 | `SW:S3` |
| `角度` | 当前舵机设角度，需确认 | `SET:S3:150?` |
| `舵机:角度` | 指定舵机设角度，需确认 | `SET:S3:150?` |
| `Y` | 确认执行 | `OK:S3:150` |
| `N` | 取消 | `CANCEL` |

> ⚠️ 校准必须在上电后直接进行（CALIB 模式）。一旦发过 `G/T/H/L`，5ms 控制循环会持续写全部舵机，手动指令会被覆盖。若要恢复校准，重新上电。

> dir 不需要重测：只转动舵机臂重新对零只影响 `zero_deg`，dir 由舵机本体安装朝向决定。若舵机本体朝向也变了，需用 +10° 法重测 dir。

---

## IMU 姿态上报（上行数据流，I 命令开关）

- 发 `I` 开启、再发 `I` 关闭，开启后 **10Hz** 固定频率（与模块输出率一致）
- 格式（参考 adc_10 多参数采集系统风格，全整数传输）：

```
R,<roll_x10>,P,<pitch_x10>,Y,<yaw_x10>,520\r\n
例: R,-12,P,34,Y,1579,520
```

| 字段 | 含义 | 说明 |
|---|---|---|
| R | 横滚 roll | 整数 = 角度×10（0.1° 分辨率，-12 = -1.2°） |
| P | 俯仰 pitch | 同上；**前倾为正、后倾为负**（实测约定） |
| Y | 偏航 yaw | 同上（Z 轴漂移，不可长期参考） |
| 520 | 帧尾 | 校验标记，末字段非 `520` 的帧丢弃 |

- 帧类型判定：逗号分割后 7 个字段且末字段为 `520` → IMU 帧
- IMU 模块：WT9011G4K，115200bps，TX → PD6(USART2_RX)
- 上报与命令回显交错出现，上位机按帧尾/前缀分发解析

## 编码器转速上报（上行数据流，J 命令开关）

- 发 `J` 开启、再发 `J` 关闭，开启后 **10Hz** 固定频率

```
E,<rpm0>,<rpm1>,<rpm2>,<rpm3>,520\r\n    例: E,0,150,0,-150,520
```

| 字段 | 含义 | 说明 |
|---|---|---|
| E | 帧标识 | 编码器转速帧 |
| rpm0~3 | 电机 A/B/C/D 输出轴转速 | 整数 RPM（带符号：正=正转），满速约 ±360（实测 50% 占空比 ≈180） |
| 520 | 帧尾 | 校验标记 |

- 转速由四路 GMR 编码器 EXTI 计数换算（100ms 采样窗口）
- 用途：① 调试显示 ② 倾斜平衡的"到速平台期"判定（固件内部使用）

---

## 上电状态

1. 12 路舵机 PWM 全开（CCR=0 无脉冲）
2. **外展 4 舵机**（1~4）100ms 错开锁到站姿角：95 / 94 / 50 / 150°
3. 大腿/小腿 8 舵机保持松弛（指令角已预置为 IK 站姿解，首次 G 不跳变）
4. **电机 PWM 启动但 CCR=0**，STBY 拉高待命，不转
5. 蓝牙发 `READY\r\n` 自检
6. 模式 = CALIB（5ms 控制循环不碰舵机），等命令

---

## 步态说明（3D IK + walk_gait）

```
5ms 控制节拍 (200Hz):
  模式机: CALIB(不动) / STAND(站立) / TROT(行走) / STEP(单步冻结)

  STAND: 足端目标 = 前移修正 + 低趴外伸(站高越低前后腿越外伸)
         → 3D IK(前后腿膝分支独立: 正常/反折) → 12舵机
  TROT:  足端轨迹(支撑60%: 贴地+30→-30mm; 摆动40%: 椭圆抬25mm)
         → 3D IK → 12舵机
         E 转圈时额外叠加重心横移 ±15mm (E:0 反向)
  STEP:  同上但行走时刻冻结, A 每次 +1/4 周期

  指数平滑: 指令角 += (目标-指令角)×速率(站0.12/走0.20) → 批量写12路
```

参数（walk_gait.c 的 g_walk_params，运行时可改）：

| 参数 | 值 |
|---|-----|
| step_len 步幅 | 60mm（T 行走）/ 0mm（W 越障原地抬）/ 30mm（F 横移，已暂停） |
| step_h 抬腿 | 25mm（T 行走）/ 70mm（W 越障）/ 40mm（F 横移，已暂停） |
| period 周期 | 1.2s |
| duty 支撑比 | 0.6 |
| stand_h 站高 | 280mm（默认，G/H/K/P 高姿态）/ 240mm（M 后顶低趴）/ 191mm（L 前顶低趴，四轮驱动） |
| foot_x_shift 前移修正 | 15mm（最终实测默认值），X: 命令仍可在线调，正值修正前倾 |
| y_shift 重心横移 | 15mm（定死，仅 E 转圈动作用），E:0 取反为逆时针 |

---

## 典型操作流程

### 调试步态

```
G  →  站立（平滑渐进）
A  →  相位0 (支撑起始)            PH:0
A  →  相位1/4 (FL+RR抬腿)         PH:90
A  →  相位1/2 (对角交换)          PH:180
A  →  相位3/4 (FR+RL抬腿)         PH:270
A  →  循环
G  →  平滑回站姿
```

### 连续行走

```
G  →  站立
T  →  相位从0起, 平滑渐入 → 连续 Trot (1.2s/周期, 步幅60mm)
G  →  平滑回站姿
```

### 五姿态切换（H / K / L / M / P）

```
H  →  狗姿态高站姿 280mm (前后腿正常膝)  → HIGH → 配 T 行走 / W 越障
K  →  前顶高站姿 280mm (前腿反折 + 后腿正常) → KNEE
L  →  低趴 191mm = K 姿态趴下 (前反折, 四足±129.5对称, 大腿≈水平+小腿垂直) → LOW → 配 R/B/S 车轮跑
M  →  低趴 240mm = 后顶版 (前腿狗腿正常 + 后腿反折膝往前突, 重心集中) → REAR
P  →  后顶高站姿 280mm = M 的高姿态版 → REARH
```

**翻膝机动**（切换时自动执行，指定腿组）：

```
需要翻的腿组足端沿地面伸到直腿点(此点两膝分支连续) → 翻转分支 → 收回到站姿点
前腿往+伸, 后腿往-伸; 回显 FLIP, 膝离地全程 ≥110mm, 总时长约 3s
```

- K↔L、M↔P 同分支，直接升降，无翻膝；其余组合自动识别需翻的前/后腿组
- 上电默认狗姿态（前后正常膝，站高 280），G = 狗高站姿（等价于按 H）
- ⚠️ 低趴 240mm（L/M）只用于四轮驱动，不要发 T。要走路先按 G 或 H。

### 前倾修正

```
身体前倾(重心偏前) → 抬前脚被压/拖地
X:10  →  足端前移 10mm, 观察身体是否回正    XSH:10
X:20  →  不够再加大                          XSH:20
X:-10 →  反了就往回调                        XSH:-10
```

- 站立/行走同时生效，行走中也可实时调
- 调好后把默认值写进 `g_walk_params.foot_x_shift` 即可永久生效

### 轮式滚动

```
R  →  四电机 30% 正转 → 往前滚
B  →  四电机 30% 反转 → 往后退
S  →  四电机全停（急停）
M1:60:0  →  单电机B 60% 反转（单独调试）
```

> 轮径 108mm（2026-08-20 更换，旧 65mm）：同占空比实际车速约 +67%（50% ≈ 180 RPM ≈ 1.0 m/s）。
> 编码器在电机输出轴上，转速读数不随轮径变（50% 仍 ≈180 RPM）。
> 站立姿态实际车身高度 = stand_h + 轮半径（代码无轮径补偿，240 → 实际 294mm）。
```

### 越障模式（W）

```
W  →  原地对角抬腿 50mm, 高站姿 280mm, **不动轮**
      (FL+RR 与 FR+RL 两组交替: 摆动相抬起→落下, 足端不前后移)
      → 配合 V:速度:转向:1 (无倾斜轮盘) 边抬腿边前进
      → 自稳自动跟随 (先 Z 标定): 支撑腿 z 补偿, 防对角支撑翘板
        (无自稳时重心偏一侧会把摆动腿压回地面, 只剩对侧腿抬着)
        **W 模式自稳无条件开启** (2026-08-26 修复: 此前经典轮盘V会清跟随标志导致W自稳丢失)
        W 模式为快速档: 50ms 更新 + 快速低通(~0.1s) + 死区0.5° + 舵机跟随2倍速
      → 重心横移补偿: 足端整体右移=身体左移 (默认 15mm, 补偿机身右侧偏重)
        调参: W:毫米 (范围 ±40, 如 W:25 加重左移; 还往右倾就加大)
        (对角支撑时绕支撑线的倾倒是静态不可控的, 重心必须摆到对角线上)

### W 越障抬腿（APP 侧约定）

- **W 按钮**：发 `W` 进入越障抬腿（回 `CLIMB`）；重复发 `W` 会重置相位（相当于重新开始）
- **重心补偿滑块**（建议放在 W 按钮旁边）：
  - 范围 **0~40**，默认 **15**，显示"重心左移补偿 mm"
  - 拖动中/松手时发 `W:毫米`，固件回 `WCOM:毫米`（APP 用回显刷新显示，不要等 WCOM 之外的状态）
  - **W 运行中发 `W:毫米` 只改补偿量**：不重置相位、不停轮，可实时观察效果
- 退出越障抬腿：发 `G`（回站姿）或 `T`（转行走）；停轮保持抬腿：`S`
- 调参口诀：机身往右倾/往右转 → 滑块加大；往左倾 → 减小；调到满意把数值反馈给固件方写死默认
S  →  只停电机, 腿继续抬 → 要停腿再发 G (G 同时停轮)
G  →  腿回站姿
T  →  退出越障回纯行走 (恢复步幅60/抬腿25)
```

### 云台控制（G:）

```
G:90:120  →  水平90° + 俯仰120° (正对前方) → 回显 GM:90,120
G:90      →  只转水平, 俯仰保持当前值
上电默认  →  90/120 正对前方 (实测确认)

水平 pan:  0~180°;  90=正对前方, <90 往右转, >90 往左转
俯仰 tilt: 75~180°; 120=正对前方, <120 往下(机械限位 75°), >120 往上
           (固件自动限幅: 超出范围按边界值)
分辨率约 9°/档
```

- 云台舵机: 180° 数字舵机 ×2, TIM13 CH1(PF8)=水平 pan, TIM14 CH1(PF9)=俯仰 tilt, 50Hz
- **上电自动回正对前方 (90/120)**
- 任何模式下都可用（与行走/站姿互不干扰）；`G` 不带冒号仍是站姿命令

### 轮盘控制约定（APP 侧）

- 轮盘**无回中**：拖到哪云台停在哪（固件不做回中，松手不动作）
- APP 拖动轮盘时以 ~10Hz 发 `G:水平:俯仰`；每次把两轴当前值一起发（只发一轴时另一轴保持）
- 方向映射（轮盘→角度）：
  - 水平轮盘右拨 → 角度**减小**（<90 往右）；左拨 → 增大
  - 俯仰轮盘下拨 → 角度**减小**（<120 往下）；上拨 → 增大（注意 75 下限，APP 侧同样把轮盘滑到头钳在 75）

### 转圈动作（E）

```
E    →  trot + 重心横移15mm, 顺时针原地转圈    SWAY:1
E:0  →  横移取反, 逆时针原地转圈               SWAY:-1
G    →  回站姿停止转圈
```

### 坡度自适应（已删除）

> 2026-08-23 从固件删除（未实测、与站立自稳职责重叠）。能力由站立自稳 + V 模式1 覆盖。

### 站立自稳（H/K 高站姿）

```
Z    →  放平地保持当前姿态静止2秒 → 标定 pitch/roll 零偏 → CAL:OK
L:1  →  开启自稳 (LV:ON; 当前姿态未标定时回 LV:NOCAL)
      →  站立静止时: 身体往哪边倾, 哪边腿伸长撑回水平 (10Hz, 低通约0.35s)
L:0  →  关闭 (LV:OFF), 总开关: 同时清 W/V模式1 的自稳跟随残留
```

- 适用姿态：仅 **H（狗高）** 与 **K（前顶高）** 280mm（P 后顶站 RR 大腿余量 7° 不启用）
- 单腿 z 补偿上限**按当前站高动态算**：`304.6 − 站高`（280≈25mm→7.5°坡、**230≈75mm→23°坡**、220≈85mm→26.5°坡、210≈95mm→30°坡）；超出后钳位，身体保留剩余倾斜
- **爬陡坡流程**：平地 `G` → `Z` 标定 → `V:..:1` 接近坡底 → `H:230` 边开边蹲（~1s 平滑）→ 上坡保持水平（≤23°）→ 回平地 `H` 站起
- **死区 ±0.7°**（2026-08-26 精度升级：1°→0.5°→实测偏敏感，折中 0.7°）：微小晃动不响应，软死区无阶跃
- **积分项**（2026-08-26 新增）：累积死区后残差，消除重心偏载的常驻倾斜（纯比例控制的稳态下垂），约 2s 收敛，抗饱和上限 pitch 3°/roll 6°；W 快速档无积分
- 生效条件：站立静止（行走 T/W/E、站起 U、翻膝、收纳 C、坐姿 O 中不叠加）**或 V 模式1 无倾斜驱动中**（自动跟随，无需 L:1，需先 Z 标定 H）
- 零偏按姿态分存（H/K 各标一次），`Z` 重复按可重新标定覆盖
- roll 符号待实测：右倾 = roll 正（若方向反了改固件一个符号）

### 摇杆遥控（APP 第四页，V 命令）

**APP 端逻辑（供 APP 开发参考）：**

```
摇杆上下: 前进/后退 → V:sp:st 的 sp 分量 (-50~+50)
摇杆左右: 左转/右转 → V:sp:st 的 st 分量 (-50~+50)
发送频率: 握住摇杆时每 50~100ms 发一次 (建议 100ms)
摇杆回中: 发 V:0:0 (固件自动渐停+回平)
姿态按钮: 直接发 G/H/K/L/M/P (现有命令)
V 命令无回显: APP 不要等应答, 状态显示用 IMU/编码器流
```

**固件行为：**

```
V:30:0   → 四轮 30% 占空比前进 (0.5s 斜坡渐入, 1:1 映射)
V:-20:0  → 四轮 20% 占空比后退
V:0:40   → 原地右转 (左轮正转/右轮反转, 各40%)
V:30:15  → 前进 + 右转 (左45% / 右15% 差速)
V:0:0    → 渐停 (带刹车抬头补偿), 0.5s 内停稳
S        → 急停 (立即停 + 回平)
速度换算: V 值 = 占空比% (1:1), 满速 V:50 ≈ 180 RPM (3.6 RPM/单位)
```

**模式 1（无倾斜补偿移动轮盘，`V:sp:st:1`）：**

```
V:30:0:1   → 无倾斜补偿前进 30% + 高站姿280 + 自稳保持平台水平
V:0:30:1   → 原地右转, 无压弯
行为:
- 无倾斜平衡: 起步不低头/不压弯, 身体水平完全交给 IMU 自稳层
- 高站姿: 当前反折膝时先自动翻膝回 H (回 FLIP), 翻完前驱动命令忽略; 正常膝时**按当前站高行驶**（配合 `H:230` 蹲低爬陡坡, 不强制 280）
- 自稳自动跟随: 不需先发 L:1, 但 H 姿态必须先 Z 标定过 (未标定则只驱动不自稳)
- 高频流不回显, APP 不要等应答
- 退出: 回模式0 (V:0:0 两参) 或 S/姿态命令
```

### 倾斜平衡（V 摇杆 + D 方向按键）

**V 摇杆（随加速过程动态收放）：**

| 场景 | 补偿动作 | 幅度 |
|------|---------|------|
| 起步加速（前进） | 平台主动**低头**（前腿 z 缩短/后腿 z 伸长） | ∝(命令−实际占空比)，上限 15mm ≈ 4.5° |
| 起步加速（后退） | 平台主动**抬头**（车身前栽的反向补偿） | 同上反向 |
| 刹车减速 | 平台主动**抬头**（前进刹车）/ **低头**（后退刹车） | 同上 |
| 左转/右转 | 平台向弯内**压弯**（左转左边低、右转右边低） | ∝转向量，上限 10mm ≈ 2.7° |
| 到速 | 编码器转速**平台期**判定（300ms 窗口增量 <2 RPM）→ 提前回平 | 0.3s 渐变 |
| 兜底 | 占空比斜坡完成 → 倾斜自动归零；编码器无信号时靠此兜底 | — |

**D 方向按键（固定倾斜，全程保持）：**

| 方向 | 轮速 | 固定倾斜 |
|------|------|---------|
| `D:0` 前进 | spd 前进 | 低头 10mm 保持 |
| `D:1` 后退 | spd 后退 | 抬头 10mm 保持 |
| `D:2` 左前 | 前向 3/4 + 左转 3/5（弧线明显） | 低头 6mm + **左倾 10mm（左边低）** 保持 |
| `D:3` 右前 | 前向 3/4 + 右转 3/5 | 低头 6mm + **右倾 10mm（右边低）** 保持 |

- **只有停止（`S`）才回平**，行驶全程保持倾斜（与 V 的到速回平行为不同）
- **切换动作时先回平再倾斜**：换方向（如左前→右前）或从摇杆切到按键时，平台先回平（约 0.2s），到位后再压新方向（约 0.2s），动作分两段，不直接横摆

### 按键驾驶新页（D 模式 1，`D:方向:速度:1`）

**固件行为：**

| 方向 | 轮速 | 倾斜 |
|------|------|------|
| `D:0:30:1` 前进 | 左右 30% | **无倾斜补偿** |
| `D:1:30:1` 后退 | 左右 −30% | 无 |
| `D:2:30:1` 左转 | **左 20% / 右 30%**（25±5 小差速） | 无 |
| `D:3:30:1` 右转 | 左 30% / 右 20% | 无 |

- 斜坡 0.5s 渐入（与 V 同机制），`S` 停止
- **自稳跟全局开关走**：`L:1` 开着则本页行驶中身体自动调平（需 H/K 高站姿 + Z 标定）；`L:0` 则纯驾驶不自稳（与 V 模式1 的"自动跟随"不同）

**APP 侧约定（独立页面）：**

- 4 个大按钮：前进 / 后退 / 左转 / 右转，按住发 `D:方向:30:1`，松开发 `S`（按住走松开停）
- **加减速按钮**：加速发 `U:1`、减速发 `U:0`（步进 5，范围 10~50）；行驶中立即生效；**长按重复**：按下瞬间先发一次，之后每 ~500ms 重复一次（实测 300ms 偏快），松手停止
- **速度实时显示**：用 `U:1`/`U:0` 回显 `SPD:数值` 和 `D` 回显 `DRV:dir:spd` 刷新当前速度
- 一个停按钮：发 `S`
- 自稳状态显示：读全局 `L:1`/`L:0` 开关状态（本页不自带自稳，由用户全局控制）；建议页面上放个自稳开关按钮同步全局状态

### 单腿抬腿（N:，8 按键）

**固件行为：**

```
N:0:1  →  左前腿抬起前伸 (50mm高 × 80mm前伸, 0.8s 平滑) → 悬空保持 → LG:0,1
N:0:0  →  左前腿慢慢放下 (1.2s) → 停在前伸位着地 (x保持+80) → LG:0,0
腿号: 0=FL 1=FR 2=RL 3=RR; 动作: 1=抬 0=放
```

- **互斥**：仅**空中腿**阻塞——抬起/悬空/放下中按其它腿的抬键 → 回 `LG:BUSY`；**落地后立即释放**，可接着抬下一条腿；非站立（行走/翻膝/收纳/站起/坐姿）→ 回 `LG:NO`
- **前伸记忆**：每腿独立记忆落地前伸量（上限 80mm），可**四腿依次迈出**（各前伸一次 = 四足前伸 80mm 姿态，身体不位移）；已达上限的腿再按抬 = 原地抬起不追加前伸；姿态命令全部滚回
- **重心转移**：抬起过程中三条支撑腿自动横移 15mm（远离抬起腿，重心移进支撑三角形防倾覆），放下完成后自动回中
- **自稳全程保持**：抬起的腿不参与自稳修正，其余三条支撑腿继续调平（L:1 或 V模式1/W 跟随均适用）
- **行进中可用**：轮式驱动（V/D 按键页）时抬腿，其余三轮继续走；trot 行走中不可用
- **抬起中按放键**：立即从当前位置平滑转放下（不跳变）
- **收回**：任何姿态命令（G/H/K/L/M/P 等）自动收回空中腿；行走命令（T/W/E/F/A）自动放下
- **放下无触地检测**：放到站立高度即视为着地（平地使用；无足端传感器）
- 抬起的腿的轮子保持转动（不单独停轮）

### 上台阶双腿模式（N:4 / N:5）

```
N:4:1  →  前双腿收起抬高 50mm 直抬 (两条腿同时) → 保持
N:4:0  →  前双腿同时放下 (1.2s)
N:5:1 / N:5:0 → 后双腿同样
```

- **按住抬/松开放**：APP 按下发 `N:4:1`（或 `N:5:1`），松开发 `N:4:0`；按住期间重复发 1 是安全的（回 `LG:4,1` 确认，不重置）
- **台阶阶段自稳/倾斜让位**：双腿模式期间身体需自然俯仰（绕后轴翘起），自稳与倾斜平衡全程不叠加；放下完成自动恢复
- **互斥**：双腿模式与单腿 N 互斥（都回 `LG:BUSY`）；姿态命令收回
- 用法：前轮顶到台阶 → 按前腿键 + 轮盘前推 → 前轮滚上台阶 → 松开前腿键 → 按后腿键 + 前推 → 后轮滚上 → 松开

**APP 侧约定（独立页面，8 抬放键 + 1 收回键）：**

- 2×2 按键阵列 + 每个腿 2 个键（抬/放），如"左前抬 / 左前放"……
- 按键按下发 `N:腿:1`（抬）或 `N:腿:0`（放），**不用按住**（动作自动执行完）
- **上台阶 2 按钮**（建议放同一页）：
  - "前腿抬"按钮：**按住发 `N:4:1`，松开发 `N:4:0`**（按住期间可重复发确认）
  - "后腿抬"按钮：按住发 `N:5:1`，松开发 `N:5:0`
  - 抬放全程配合轮盘（`V:..:1`）前推，腿只做辅助
- 状态显示用回显：`LG:腿,1`（抬）、`LG:腿,0`（放/已放）、`LG:BUSY`（先放当前腿）、`LG:NO`（先回站立）
- **"收回"按钮（必放，发 `G`）**：
  - 空中腿立即收回站立位；前伸着地的腿滚回原位
  - 注意 `G` 是完整姿态命令：同时会把站高回到 280（如在 H:230 低站姿会跟着站起）——期望只收腿时请留意
  - 回显 `STAND...` → `OK:STAND`，APP 用 LG 状态同时清零
- 过渡速率 0.25mm/5ms（约 300ms），起步不猛
- V 与 D 互斥：谁最后按下谁接管；摇杆代码保留

### 收纳与站起（C / U）

```
C  →  慢速缓降 (约2~3s) 到 72mm 贴地趴:
      四腿伸直外展 (前+297/后-297), 膝高约67mm, 肚皮离地约53mm
      → 断电: 肚皮再落 ~53mm (108mm大轮抬高车身, 落差变大需实测砸落力度)
上电 → 外展锁定角度与贴地趴兼容 (q1≈0), 不会扭腿
U  →  规划式站起 (回显 RISE → 完成回 LOW, 上电后直接可用):
      单段 (3.5s): 先顶升后收腿 → 前顶低趴 191mm (与趴姿同膝分支, 免翻膝)
      足端沿 大腿(q2±90)+小腿(q3) 双边界内收 (低站高时腿只能近伸直外伸,
      收拢量随站高上升逐步放开, 低力矩)
      + 重心挪移: h>100mm 后重心渐移向左后角(RL) 15/10mm, 卸载右前腿(FR)
      完成后 = 前顶低趴姿态: 直接发 R 四轮驱动, 或 G/K 再升到高站姿
```

> 收纳姿态下勿发 T；断电前先按 C；上电站起用 U（G 也可强起，但力矩大，仅兜底）。

```
F     →  自动切狗姿态280 + 四腿外展横向扫步 + 原地抬腿40mm, 身体向右
F:0   →  向左横着走
G     →  腿回站姿停止横移
```

### 校准舵机（已启用，上电后、发 G/T 前使用）

```
5        →  SW:S5
150      →  SET:S5:150?
Y        →  OK:S5:150
```

---

## 电流保护

| 动作 | 保护 |
|------|------|
| 上电外展锁定 | 4 舵机 100ms 错开 |
| 所有模式切换 | 指数平滑渐进（每拍只逼近目标的 12~20%） |
| 连续 Trot | 每拍角度变化微小，无需额外处理 |

---

## 调试回显

| 上行 | 含义 |
|------|------|
| `UNK:xxx\r\n` | 固件收到无法识别的命令，原样回显（排查用） |
| `READY\r\n` | 上电自检（TX/DMA 通道正常） |
| `FLIP\r\n` | 翻膝机动开始（H/K/L/M/P 姿态切换中需翻膝时自动触发，约 3s 完成） |
| `CALIB...` / `CAL:OK` | 自稳标定：开始 / 完成（零偏已存，可开自稳） |
| `IMU:ON` / `IMU:OFF` | IMU 上报开关回显 |
| `R,x,P,y,Y,z,520` | IMU 角度帧，I 开启后 10Hz（见"IMU 姿态上报"节） |
| `J:ON` / `J:OFF` | 编码器转速上报开关回显 |
| `E,e0,e1,e2,e3,520` | 编码器转速帧，J 开启后 10Hz（见"编码器转速上报"节） |
| `DBG2:CR1=... ISR=...` | I 按下后的 USART2 寄存器 + 收发计数诊断（排查接收链用） |
| `IMU:NO DATA raw=N frames=N` | I 开启但 5s 无有效帧的告警（每 2s 一次，排查接收链用） |
| `SIT` | 坐姿命令回显（O，后腿需翻膝时先回 `FLIP`） |
| `TROTB` | 倒着走回显（T:-1） |
| `GM:pan,tilt` | 云台角度设置回显（G:水平:俯仰） |
| `WCOM:毫米` | W 重心补偿量回显（W:毫米 命令，APP 滑块用） |
| `LG:腿,1` / `LG:腿,0` / `LG:BUSY` / `LG:NO` | 单腿抬腿回显（N:命令：抬/放/互斥忙/非站立） |
| `SPD:数值` | 按键页速度档回显（U:1/U:0，APP 实时显示用） |
| `WID:毫米` | 站姿宽度偏移回显（Y:毫米） |

---

### 连接页调试参数（APP 侧约定）

**站姿宽度偏移滑块**（放连接页，2026-08-25）：

- 范围 **−40 ~ +40**，默认 **0**，显示"站姿宽度偏移 mm"
- 拖动中/松手时发 `Y:毫米`，固件回 `WID:毫米`（APP 用回显刷新显示）
- 语义：正值 = 每足足端向外偏移（支撑面加宽），负值 = 收窄；**实测方向待确认**（外展 y 通道符号正在标定中，若 Y:15 时足端实际往里收，固件方翻符号）
- 生效范围：站立/收纳/站起/坐姿、V/D 驾驶、N 抬腿、W 原地抬腿（T/E/F 行走不生效）
- 参数不持久化（断电回 0）；调定后由固件方写死默认

---

## 已知兼容性注意

- STM32H7 D-Cache：TX 前刷缓存（`SCB_CleanDCache_by_Addr`），SRAM 缓冲区不回旧数据
- MPU Region 1 必须是 512KB 对齐的 `0x24000000`（整个 D1 RAM 非缓存）

---

## 横屏遥控界面方案（APP 第 4 页，供 APP 开发方）

> 本方案**只改 APP，固件零改动**：全部使用现有命令，状态显示靠命令回显在 APP 侧维护。

### 布局（横屏，左手摇杆 + 右手按钮区）

```
┌───────────────────────────────────────────────┐
│ 状态栏   姿态: 狗高 280      行为: 行走中      │
│                                               │
│   ┌──────────┐        ┌───────────┐           │
│   │          │        │  [I]  [J] │ 数据开关   │
│   │  左摇杆  │        ├───────────┤           │
│   │  (开车)  │        │ [T][W][E] │ 步态按钮   │
│   │          │        │ [R][B][S] │ 轮式按钮   │
│   └──────────┘        └───────────┘           │
│   ┌───────────────────────────────────┐       │
│   │ [G] [H] [K] [P] [L] [M] [C] [U]  │ 姿态   │
│   └───────────────────────────────────┘       │
└───────────────────────────────────────────────┘
```

### 控件 → 命令映射（全部现有命令）

| 控件 | 命令 | 发送约定 |
|------|------|---------|
| 左摇杆 | `V:sp:st` | 摇杆变化时 ~10Hz；松手发 `V:0:0`；**无回显** |
| 数据开关 I / J | `I` / `J` | 单击切换，有回显 |
| 步态按钮 | `T` / `W` / `E` | 单发，有回显 |
| 轮式按钮 | `R` / `B` / `S` | 单发，有回显 |
| 姿态按钮 | `G` `H` `K` `P` `L` `M` `C` `U` | 单发，有回显 |

### 状态栏显示方案（纯 APP 侧，回显驱动）

- APP 维护一个"当前姿态 + 当前行为"状态，**每次收到回显就更新**，不需要问机器人
- 蓝牙刚连上时状态未知 → 显示"未同步"，发一条 `G` 或等第一条回显后刷新（或引导用户按 G）

**回显 → 状态栏 映射表：**

| 收到的回显 | 姿态栏 | 行为栏 |
|-----------|--------|--------|
| `READY` | （上电初始） | 校准模式 |
| `STAND...` → `OK:STAND` | 狗高 280 | 站立 |
| `HIGH` | 狗高 280 | 站立 |
| `KNEE` | 前顶高 280 | 站立 |
| `REARH` | 后顶高 280 | 站立 |
| `LOW` | 前顶低趴 240 | 站立 |
| `REAR` | 后顶低趴 240 | 站立 |
| `PARK` | 收纳贴地趴 | 收纳中 |
| `SIT` | 坐姿（狗坐造型） | 站立 |
| `TROTB` | — | 倒着走 |
| `RISE` | — | 规划站起中（约 7s） |
| `FLIP` | （不变） | 翻膝机动中（约 3s） |
| `TROT` | — | 连续行走 |
| `CLIMB` | — | 越障模式 |
| `SWAY:1` / `SWAY:-1` | — | 转圈（顺/逆） |
| `ROLL` / `BACK` | — | 轮式前进 / 后退 |
| `STOP` | — | 停止 |
| `PH:x` | — | 单步调试 |

- 摇杆 `V` 无回显：推杆时行为栏显示"轮式驾驶"，松手（发 `V:0:0`）后回"站立"
- `FLIP` 收到后约 3s 姿态切换完成，APP 可显示"翻膝中…"动画；`FLIP` 后的最终回显（如 `LOW`/`OK:STAND`）会刷新姿态栏

### 方向显示（实时，APP 自算，无需固件配合）

页面中央可做一个方向指示（箭头/文字），**由 APP 自己的操作状态实时计算**——APP 发什么命令，箭头就显示什么：

| APP 当前操作 | 方向显示 |
|-------------|---------|
| 摇杆 sp>0, st=0 | 前进 |
| 摇杆 sp<0, st=0 | 后退 |
| 摇杆 sp=0, st>0 | 原地右转 |
| 摇杆 sp=0, st<0 | 原地左转 |
| 摇杆 sp>0, st>0 | 右前 |
| 摇杆 sp>0, st<0 | 左前 |
| 摇杆 sp<0, st>0 | 右后 |
| 摇杆 sp<0, st<0 | 左后 |
| 摇杆回中 / 无操作 | 停止 |
| 按钮 `R` / `B` | 前进 30% / 后退 30% |
| 按钮 `T` / `W` | 行走前进 / 越障前进 |
| 按钮 `E` / `E:0` | 顺时针转圈 / 逆时针转圈 |

- 摇杆方向随摇杆实时变（10Hz 发命令的同时刷新箭头），松手显示"停止"
- **实际方向核对**（可选）：轮式模式下用 `J` 流的 RPM 符号交叉验证——四轮同正=实际在前进、同负=后退、左正右负=右转、左负右正=左转

### 数据区显示（配合 I / J 流）

| 显示项 | 数据源 | 解析 |
|--------|--------|------|
| 横滚/俯仰/偏航 | `I` 流 `R,x,P,y,Y,z,520` | ÷10 = 角度，P 正=前倾 |
| 四轮转速 | `J` 流 `E,e0,e1,e2,e3,520` | 直接显示 RPM（正=正转） |

### 交互提醒

- 摇杆驾驶前先确保姿态就位（低趴 L/M 是四轮驱动姿态，狗高 G 也能开）
- 行走按钮（T/W/E）只在狗高姿态用；低趴下发 T 会钳位（APP 可把 T/W/E 置灰直到收到 `STAND`/`HIGH` 回显）
- 急停永远可用：`S` 立即停轮

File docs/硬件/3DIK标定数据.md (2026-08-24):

# 3D IK 标定数据总表

> 当前固件 (leg_ik.c 3D IK + walk_gait.c 足轨迹) 的全部实测数据。
> 数据源: 用户实测 (2026-08), 已写入代码。
> 2026-08-20 更换 108mm 大轮（旧 65mm，半径 +21.5mm）。膝高/离地为身体系几何值（与轮径无关），实际离地 = 几何值 + 轮半径 54mm。
> 收纳 C 的车身高度由着地轮子锚定（臀高 = 72 + 轮半径），断电落差随轮径变化（见蓝牙协议文档）。

---

## 一、几何尺寸（实测）

| 参数 | 值 | 量法 | 代码位置 |
|---|-----|---|---|
| L1 大腿 | **130** mm | 髋前摆轴心 → 膝轴心 | leg_ik.h LEG_L1 |
| L2 小腿 | **180** mm | 膝轴心 → 脚底着地点 | leg_ik.h LEG_L2 |
| HIP_D 髋偏置 | **10** mm | 侧摆轴 → 大腿摆动平面 (沿用对方) | leg_ik.h LEG_HIP_D |
| BODY_BL 前后髋距 | **380** mm | 前腿髋轴 → 后腿髋轴 | leg_ik.h BODY_BL |
| BODY_BW 左右髋距 | **180** mm | 左腿侧摆轴 → 右腿侧摆轴 | leg_ik.h BODY_BW |
| stand_h 站高 | **240** (低) / **280** (高) mm | 低=四轮驱动低趴(前后腿外伸) / 高=行走 (腿伸直时310) | walk_gait.c |
| 轮径 | **108** mm | 轮胎外径（2026-08-20 更换，旧 65mm；代码无轮径补偿，实际车身 = stand_h + 轮半径） | 硬件 |

---

## 二、舵机标定（12 个零点 + dir，实测）

> servo = zero_deg + dir × 几何角
> 零点定义: q1 腿竖直 / q2 大腿竖直 / q3 大小腿成直线

| 腿 | q1 侧摆 | q2 大腿 | q3 小腿 |
|----|---|---|---|
| FL 左前 | 95 / **+1** | 115 / **-1** 🔧 | 93 / **+1** |
| FR 右前 | 95 / **-1** ⚠️ | 150 / **+1** 🔧 | 135 / **-1** |
| RL 左后 | 50 / **-1** | 110 / **-1** | 165 / **+1** |
| RR 右后 | 150 / **+1** ⚠️ | 230 / **+1** | 185 / **-1** 🔧 |

> 🔧 2026-08-16 重装舵机臂（装臂参考角 135° 法），旧值: FL大腿212 / FR大腿65 / RR小腿90。dir 未变。
> 🔧 2026-08-21 FR 外展 94→99（外展偏多，往回收 5°；角度<99 仍为往外）。
> 🔧 2026-08-23 FR 外展 99→91（又偏内了，往外展 8°；角度<91 为往外）。
> 🔧 2026-08-23 FR 外展 91→95（91 太外，往回收 4°；角度<95 为往外）。
> ⚠️ 2026-08-20 RR 落地点偏前（疑似小腿零位偏 ~6°）：代码暂用 foot_x_corr[3]=-20mm 补偿；**待机械重标 RR 零位后移除**。
> ⚠️ 右腿侧摆 dir 经 +10° 实测确认 (FR: 角度<95 往外; RR: 角度>150 往外)。
> 对方仓库里这两处符号相反, 协同合并时以本表为准。

---

## 三、步态参数（walk_gait.c 运行时可调）

| 参数 | 值 | 说明 |
|---|-----|---|
| step_len | 60 mm (T) / 0 mm (W) | 步幅 / 越障原地抬 |
| step_h | 25 mm (T) / 50 mm (W) | 抬腿（2026-08-24 实测：W 抬 70mm 时后腿几乎抬不动——RR大腿266°/RL小腿261°贴270°伺服极限；50mm 时 RR大腿259°/RL小腿250°，前腿余量39°起，前后腿抬升才一致） |
| period | 1.2 s | 周期 |
| duty | 0.6 | 支撑相比例 |
| stand_h | 240 (低) / 280 (高) mm | 站高：低趴=四轮驱动用（前后腿外伸，不走路）/ 高=行走用；上电与 G 默认 280 |
| foot_x_shift | 15 mm | 前倾修正（最终实测值，X: 命令可在线调） |
| y_shift | 15 mm | 重心横移（定死，仅 E 转圈动作用，T/W 不含） |

---

## 四、已知余量（2026-08-20 低趴 240mm 版，X=15）

**L 低趴 191mm（前反折 + 后正常，四足 ±129.5 对称展开，大腿≈水平+小腿垂直的视觉姿态，四轮驱动）：**

| 关节 | 站定舵机角 | 余量 | 备注 |
|---|---|---|---|
| FL 小腿 (零93) | 8.0° | 8° | 全机最紧 (q3=-85°, 视觉姿态代价) |
| RL 小腿 (零165) | 250.0° | 20° | q3=+85° |
| FR 大腿 (零150) | 235.0° | 35° | q2=+85° |
| 其余 9 舵机 | — | ≥30° | 无钳位 |

- 四腿镜像对称：大腿 ±85°（≈平行地面），小腿 ∓85°（垂直地面），膝高 180mm（实际离地 234mm）
- 支撑中心 = 身体正下方，四轮载荷均衡
- 2026-08-21 由 240mm/前+100/后-160 改为视觉姿态（用户要求大腿水平+小腿垂直）

**K 高站姿 280mm（反折膝，前足+15）：** 前腿 q2=+33.1°/q3=-51.2°，膝高 171mm，最小余量 42°。

**P 高站姿 280mm（前正常 + 后反折膝，足端+15）：**

| 关节 | 站定舵机角 | 余量 | 备注 |
|---|---|---|---|
| RR 大腿 (零230) | 263.1° | 7° | 全机最紧 (q2=+33.1°) |
| RR 小腿 (零185) | 236.2° | 34° | q3=-51.2° |
| 其余 10 舵机 | — | ≥77° | 无钳位 |

- 后腿反折：大腿前摆 33.1°，膝后折 51.2°，**膝高 171mm**，膝盖顶在髋前 71mm（收进车身下方）

**M 低趴 240mm（前正常 + 后反折膝，前足 +45 / 后足 -120，四轮驱动）：**

| 关节 | 站定舵机角 | 余量 | 备注 |
|---|---|---|---|
| RR 小腿 (零185) | 246.0° | 24° | 全机最紧 (q3=-61°) |
| FR 小腿 (零135) | 57.7° | 58° | q3=+77.3° |
| RL 小腿 (零165) | 104.0° | 104° | 反折后完全放松 |

- 前腿狗腿：大腿后摆 35.4°，膝前折 77.3°，膝高 134mm（实际离地 188mm）
- 后腿反折：大腿前摆 9.4°（收进身体下方），膝后折 61°，膝高 112mm（实际离地 166mm），膝盖往前突
- 与 L（前顶版）相比：后腿不再水平后伸，整机更紧凑，后腿舵机全部离开极限区

**H 高站姿 280mm（正常膝，行走全程扫描）：** 12 舵机全部无钳位，最小余量 ≥35°，RR 抬腿 25mm 满抬。

**站立自稳（2026-08-23，L:1/L:0，H/K 专用）：** 单腿 z 补偿上限**按站高动态**（304.6−站高，含 5mm 直腿点安全余量）。280 站高 ≈25mm（≈7.5°坡，≈关节角变 16°）：H（≥35°）/K（≥42°）余量足够；**P 不启用**（RR 大腿 7° 余量）。几何上限本质：280 站高足端 x=15 时腿长 D=280.4，直腿点 310 → 前腿最多伸 ~29.6mm；**站得越低伸腿余量越大**：230 站高 ≈75mm→23°坡、220 ≈85mm→26.5°坡、210 ≈95mm→30°坡（H:高度 命令配合爬陡坡）；roll 上限 ≈16°（侧垫 ≤50mm，BW=180 半宽 90mm，与站高关系小）。

**坐姿 O（前腿竖直伸直 x=0/z=310 + 后腿反折深蹲 x=-80/z=240，狗坐造型）：**

| 关节 | 站定舵机角 | 余量 | 备注 |
|---|---|---|---|
| RR 小腿 (零185) | 256.7° | 13.3° | 全机最紧 (q3=-71.7°) |
| RR 大腿 (零230) | 254.1° | 15.9° | q2=+24.1° |
| 前腿 | q2≈-1°/q3≈+1.6° | 大 | 竖直伸直（直腿点缩放，视觉笔直） |

- 车身自然抬头约 10.4°（前腿 310 / 后腿 240 的 z 差动），四轮着地
- 2026-08-21 新增（O 命令）

**翻膝机动（H↔K / H↔L 切换）：** 在 240mm 高度（或 280 原地）前腿足端伸到直腿点 x=√(310²-h²) 再收回，中点翻转膝分支（两分支在直腿点连续）。全程前膝高 ≥110mm，无磕地。

**U 站起阶段A 足端轨迹（2026-08-21 修复）：** 前腿(反折)/后腿(正常)足端 x 沿双边界内收：
- 大腿边界：x ≥ 130+√(32400−h²)（h<180 时 q2=±90 限制，低处腿只能近伸直外伸；h≥180 放开）
- 小腿边界：前腿 x ≥ √(53361−h²)（FL 小腿 q3=−85）/ 后腿 x ≥ √(43594−h²)（RL 小腿 q3=+97）
- 修复前只限小腿：h=72 时要求前足 x=219.5，实际需 q2=122.8°（限位 ±90）→ IK 钳位 → 前腿被指令压进地面，FR 堵转。修复后低处足端保持 ~295mm 外伸，随顶升逐步收拢。
- 2026-08-21 修复2：上电后按 U 时，指令角预置为 280 站姿解（为"首次 G 不跳变"设计），而实际腿在趴姿 → 大腿指令从站姿角爬向趴姿角，前腿乱扫（FL/FR 不对称、FR 堵转）。现 U 命令先按趴姿 IK 重同步指令角，再开始顶升。
- 2026-08-21 改版：U 终点由"240 翻膝+280"改为**前顶低趴 191mm**——趴姿（前反折+后正常）与 L 同膝分支，免翻膝；终点足端 ±129.5 恰好落在小腿边界上，顶升行程 119mm（原 208mm）。完成后直接 R 可四轮驱动。

> 低趴高度的本质约束是**髋舵机力矩**：力矩 ≈ 单腿承重 × 足端离髋距离，趴得越低足端摊得越远、力矩越大。
> 240mm 为当前值（2026-08-20 因 108mm 大轮负载增大、FR 站起堵转，由 220 上调；220 下余量最紧 20°/12°，240 下 32°/24°）。
> 低趴只用于四轮驱动，不要发 T。

---

## 五、历史数据（已废弃，仅存档）

旧站姿标定 (STAND_POSE 目测法): 大腿 240/35/135/200, 小腿 153/74/220/30 —— 已被几何零点 + IK 解算取代, 仅外展列 (95/99/50/150) 仍用于上电锁定。

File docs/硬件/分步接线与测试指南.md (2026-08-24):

# 分步接线与测试指南

> 重新接线用：按 蓝牙 → IMU → 电机驱动 → 舵机 四步走，每步接完立刻测试，通过再进下一步。
> 引脚定义以 [控制板引脚分配表.md](控制板引脚分配表.md) 为准，本文只列本次要接的信号。
> **每步接线前断电，接完检查无误再上电。**

---

## 通用电源规则（重要）

> ⚠️ **你的电源拓扑：主控由电机驱动模块供电** —— TB6612 模块的 5V 输出（板载稳压）接到主控，电机电源 VM 是**全机总开关**：VM 一上电，主控、蓝牙、IMU 跟着才有电。

| 电源 | 供谁 | 上电顺序 |
|---|---|---|
| 电机电源 VM | TB6612 VM → 模块 5V 输出 → **STM32 + 蓝牙 + IMU** | **最先上**（总开关） |
| 舵机电源 | 3 块舵机驱动板 | **最后上**（舵机电流大，防拉垮主控） |

- **所有 GND 共地**：主控 GND = 蓝牙 GND = IMU GND = 两个 TB6612 GND = 3 块舵机板 GND = 各电源地
- 断电顺序反过来：先断舵机电源，最后断电机电源（主控掉电）
- **阶段 1/2 还没接电机模块时**：主控临时用 USB / 调试器供电测试（或先把 TB6612 模块的电源和 5V→主控接好，提前完成阶段 3 的电源接线）
- 电机电源先上电的瞬间（主控启动前）轮子轻微抖一下正常——MCU 启动后立即接管 STBY

---

## 阶段 1：蓝牙 HC-05

### 接线

| HC-05 引脚 | 接到 | 说明 |
|---|---|---|
| VCC | 5V | 主控 5V |
| GND | 主控 GND | 共地 |
| **TXD** | **PB11** (USART3_RX) | HC-05 发 → STM32 收 |
| **RXD** | **PB10** (USART3_TX) | STM32 发 → HC-05 收 |

### 测试（手机蓝牙串口助手，115200）

| # | 操作 | 预期 |
|---|---|---|
| 1 | 上电 | 收到 `READY`；可能混有 `IMU:NO DATA`（IMU 还没接，正常） |
| 2 | 发 `G` | 回 `STAND...` → `OK:STAND`（舵机没接也不影响回显） |
| 3 | 发 `M0:50:1` | 回 `MA:50:1` |
| 4 | 发 `C` | 回 `PARK` |

**判据**：发什么回什么、不丢字节 → 蓝牙链路 OK，断电进入下一阶段。

---

## 阶段 2：IMU WT9011G4K

### 接线

| IMU 引脚 | 接到 | 说明 |
|---|---|---|
| VCC | 5V | |
| GND | 主控 GND | 共地 |
| **TXD** | **PD6** (USART2_RX) | IMU 发 → STM32 收（**唯一必需数据线**） |
| RXD | PD5 (USART2_TX) | 可不接（上电环回自测才用到） |

### 测试

| # | 操作 | 预期 |
|---|---|---|
| 1 | 上电 → 发 `I` | 回 `IMU:ON`；约 1s 后一行 `DBG2:CR1=... raw=N frames=N`（frames 在涨） |
| 2 | 等 2~3 秒 | 每 100ms 一行 `R,x,P,y,Y,z,520`；`IMU:NO DATA` 告警消失 |
| 3 | 手动前倾 IMU | P 值 ÷10 往**正**走；后倾往负 |
| 4 | 左右滚 | R 值变化 |
| 5 | 发 `I` | 回 `IMU:OFF`，数据流停 |
| 6 | **整机断电重启** → 发 `I` | 直接有数据流（**不用重插线**）——验证上电时序自愈 |

**判据**：10Hz 数据流正常、符号方向对、断电重启自愈 → OK，断电进入下一阶段。

---

## 阶段 3：电机驱动（TB6612 ×2 + 编码器）

### 接线

**2 路模块（Motor A/B = 前轮）**

| TB6612 | 接到 |
|---|---|
| PWMA | PA8 |
| AIN1 / AIN2 | PE0 / PE1 |
| PWMB | PA9 |
| BIN1 / BIN2 | PE2 / PE3 |
| STBY | PA10 |
| VCC | **5V 输出 → 主控 5V**（板载稳压给全机供电，不要外接 5V） |
| GND | 主控 GND + 电机电源地 |
| VM | 电机电源（总开关） |
| AO1/AO2 | Motor A 两根线（左前轮，正反无所谓） |
| BO1/BO2 | Motor B 两根线（右前轮） |

**4 路模块（Motor C/D = 后轮，只用 CH3/CH4）**

| TB6612 | 接到 |
|---|---|
| PWMC | PB8 |
| CIN1 / CIN2 | PB5 / PB6 |
| PWMD | PB9 |
| DIN1 / DIN2 | PB7 / PB12 |
| STBY | PA10（与 2 路模块并联） |
| VCC | 两个模块 5V 输出并联后接主控 5V（同源，不要重复外接） |
| GND | 主控 GND + 电机电源地 |
| VM | 电机电源（总开关，可与 2 路模块 VM 并联） |
| CO1/CO2 | Motor C 两根线（左后轮） |
| DO1/DO2 | Motor D 两根线（右后轮） |

**编码器（GMR，在电机轴上）**

| 编码器 | A 相 | B 相 |
|---|---|---|
| 1（左前） | PE7 | PE8 |
| 2（右前） | PE9 | PE10 |
| 3（左后） | PE11 | PE12 |
| 4（右后） | PE13 | PE14 |

### 测试

| # | 操作 | 预期 |
|---|---|---|
| 1 | 上电 | 上电瞬间可能轻微抖一下，随后四轮静止，无自转 |
| 2 | `M0:50:1` | **只有左前轮转**，转速中等；方向随便（下一条核对） |
| 3 | `M1:50:1` → `M2:50:1` → `M3:50:1` | 依次只有右前 / 左后 / 右后轮转 → 通道映射确认 |
| 4 | `R` | 四轮同向转（前进，30%） |
| 5 | `B` | 四轮反向（后退） |
| 6 | `S` | 全停 |
| 7 | `J` | 回 `J:ON`，之后每 100ms `E,e0,e1,e2,e3,520`；`R` 时四个值一起变正（50% ≈180 RPM 不随 108mm 轮变） |
| 8 | `M0:50:1` | **只有 e0 变** → 通道映射核对；`S` 停 |
| 9 | `J` | 回 `J:OFF` |

**判据**：四个电机通道/方向可控、编码器四通道一一对应 → OK，断电进入下一阶段。
⚠️ 若电机转但 e 值全 0 → 编码器接线/EXTI 问题，修好再往下。

---

## 阶段 4：舵机（3 块驱动板 + 12 舵机）

### 接线

**模块 A 外展板** → 舵机电源 VCC，GND 共地

| 板通道 | 舵机 | 接到 |
|---|---|---|
| CH1 | Servo 1（左前外展） | PA0 |
| CH2 | Servo 2（右前外展） | PA7 |
| CH3 | Servo 3（左后外展） | PD15 |
| CH4 | Servo 4（右后外展） | PD14 |

**模块 B 大腿板**

| 板通道 | 舵机 | 接到 |
|---|---|---|
| CH1 | Servo 5（左前大腿） | PB0 |
| CH2 | Servo 6（右前大腿） | PB1 |
| CH3 | Servo 7（左后大腿） | PD13 |
| CH4 | Servo 8（右后大腿） | PD12 | 

**模块 C 小腿板**

| 板通道 | 舵机 | 接到 |
|---|---|---|
| CH1 | Servo 9（左前小腿） | PA1 |
| CH2 | Servo 10（右前小腿） | PA2 |
| CH3 | Servo 11（左后小腿） | PA3 |
| CH4 | Servo 12（右后小腿） | PB14 |

**舵机本体**：3 块板每板 4 路信号 + 舵机电源 + GND。舵机编号印在线上或按 [控制板引脚分配表.md](控制板引脚分配表.md) 的映射速查核对。

### 测试

| # | 操作 | 预期 |
|---|---|---|
| 1 | 先上主控电，**再上舵机电源** | 12 舵机无乱动；随后 4 个外展舵机**间隔约 100ms 逐个**锁到 95 / 99 / 50 / 150°（每锁一个能听到"咔"一下） |
| 2 | 校准抽查 | `S1:95` `S2:94` `S3:50` `S4:150` 回显对应值，外展微动/不动 |
| 3 | `G`（机身装好时） | 回 `STAND...` → `OK:STAND`；**扶稳机身**，缓慢站起 280mm 狗姿态，大腿小腿同步到位 |
| 4 | `L` → `K` | 低趴 240 → 升站（慢速约 1.5s），无滋滋堵转 |
| 5 | 姿态矩阵 | `G → K → L → M → P → H → L → K → M → G`，按预期回显 + 动作 |
| 6 | `T` | 四轮 10% 助走 + trot 前进，RR 落点与其余腿对齐（−20mm 修正生效） |
| 7 | `C` → 断电落地 | 慢速贴地趴；断电肚皮再落 ~53mm，听砸落力度 |
| 8 | 上电 → `U` | 回 `RISE`，约 7s 规划站起 |

**判据**：上电外展逐个锁定、姿态矩阵全过、T 行走协调、C/U 正常 → 全部完成。

---

## 阶段 5：云台舵机（2 路，可选）

### 接线

| 舵机 | 轴 | 信号线 | 电源 |
|---|----|---|---|
| Gimbal 1 | 水平 pan | **PF8** | 舵机电源（与腿舵机同轨）+ 共地 |
| Gimbal 2 | 俯仰 tilt | **PF9** | 同上 |

> 云台舵机用普通三线舵机线：信号线接 PF8/PF9，正极接舵机电源，地线共地。

### 测试

| # | 操作 | 预期 |
|---|---|---|
| 1 | 上电 | 云台自动回**正对前方**（水平 90 / 俯仰 120） |
| 2 | 发 `G:60:120` | 回 `GM:60,120`；水平右转 30°（<90 往右） |
| 3 | 发 `G:90:75` | 回 `GM:90,75`；俯仰向下 45°（机械限位） |
| 4 | 发 `G:90:180` | 回 `GM:90,180`；俯仰向上到顶 |

**判据**：上电不动、命令后两轴分别对应 pan/tilt 动作 → OK。

---

## 全部完成后的快速回归（10 分钟）

```
上电 → READY → I(IMU流) → J(编码器流) → G → T → S → G → W → S → G
→ L → R → S → K → C → 断电 → 上电 → U → G
```

任何一步异常：记下命令 + 回显 + 现象，发我。

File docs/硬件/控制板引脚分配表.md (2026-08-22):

# 控制板引脚分配表

> MCU: STM32H743ZITx (LQFP144) | 主频: 480MHz (HSI→PLL) | 日期: 2026-08-08

---

## 一、摄像头 — DCMI 8-bit 并行接口（⚠️ 2026-08-22 已废弃，摄像头/LCD 移除）

| 引脚 | 功能 | AF | 方向 | 速度 | 上下拉 | 备注 |
|---|---|----|---|---|---|---|
| PA4 | DCMI_HSYNC | AF13 | 输入 | VERY_HIGH | PULLUP | 行同步 |
| PA6 | DCMI_PIXCLK | AF13 | 输入 | VERY_HIGH | PULLUP | 像素时钟 (OV5640 输出) |
| PC6 | DCMI_D0 | AF13 | 输入 | VERY_HIGH | PULLUP | 数据 bit0 |
| PC7 | DCMI_D1 | AF13 | 输入 | VERY_HIGH | PULLUP | 数据 bit1 |
| PG9 | DCMI_VSYNC | AF13 | 输入 | VERY_HIGH | PULLUP | 帧同步 |
| PG10 | DCMI_D2 | AF13 | 输入 | LOW | PULLUP | 数据 bit2 |
| PG11 | DCMI_D3 | AF13 | 输入 | LOW | PULLUP | 数据 bit3 |
| PD3 | DCMI_D5 | AF13 | 输入 | VERY_HIGH | PULLUP | 数据 bit5 |
| PE4 | DCMI_D4 | AF13 | 输入 | VERY_HIGH | PULLUP | 数据 bit4 |
| PE5 | DCMI_D6 | AF13 | 输入 | VERY_HIGH | PULLUP | 数据 bit6 |
| PE6 | DCMI_D7 | AF13 | 输入 | VERY_HIGH | PULLUP | 数据 bit7 |

> D0~D7 是 8-bit 数据总线，DCMI 配置 `ExtendedDataMode = DCMI_EXTEND_DATA_8B`。OV5640 输出 RGB565（每像素 2 字节），DCMI 连续抓取。

| DMA | 流 | 方向 | 模式 | 优先级 | FIFO |
|-----|----|---|---|---|---|
| DMA2_Stream7 | — | P→M (外设→内存) | CIRCULAR | HIGH | HALF FULL |

| 中断 | 优先级 |
|---|---|
| DCMI_IRQn | 0,0 |
| DMA2_Stream7_IRQn | 0,0 |

---

## 二、LCD — SPI6（⚠️ 2026-08-22 已废弃）

| 引脚 | 功能 | AF | 备注 |
|---|---|----|---|
| PG8 | SPI6_NSS | AF5 | 片选 (CS)，硬件 NSS 脉冲模式 |
| PG13 | SPI6_SCK | AF5 | 时钟 (60MHz, BRP=2) |
| PG14 | SPI6_MOSI | AF5 | 主机输出 (单线模式，无 MISO) |

### LCD 控制 GPIO

| 引脚 | 功能 | 方向 | 备注 |
|---|---|---|---|
| PG12 | LCD_BL | 推挽输出 | 背光 (1=亮, 0=灭) |
| PG15 | LCD_DC | 推挽输出 | 数据/命令选择 (1=数据, 0=命令) |

> LCD 型号: 1.54 寸 ST7789V, 240×240。SPI 仅发不收（单线模式），NSS 硬件自动脉冲。无 RESET 脚（硬件上拉到 VCC）。

---

## 三、摄像头控制 — SCCB (软件模拟 I2C) + 电源（⚠️ 2026-08-22 已废弃）

| 引脚 | 功能 | 方向 | 备注 |
|---|---|---|---|
| PF14 | SCCB_SCL | 开漏输出 | 时钟 (软件模拟, ~100kHz) |
| PF15 | SCCB_SDA | 开漏输出 | 数据 (软件模拟) |
| PF13 | PWDN | 推挽输出 | OV5640 掉电控制 (0=正常, 1=掉电) |

> SCCB 兼容 I2C，用于写 OV5640 寄存器配置。SCL/SDA 外部需 4.7kΩ 上拉电阻。

---

## 四、电机 — 4× TB6612 DC Motor

### PWM 输出 (10kHz, PSC=239, ARR=99)

| 电机 | 腿 | 引脚 | 定时器通道 | AF |
|---|----|---|---|-----|
| Motor A | Leg 1 | PA8 | TIM1_CH1 | AF1 |
| Motor B | Leg 2 | PA9 | TIM1_CH2 | AF1 |
| Motor C | Leg 3 | PB8 | TIM16_CH1 | AF1 |
| Motor D | Leg 4 | PB9 | TIM17_CH1 | AF1 |

> TIM1 是高级定时器，需 `__HAL_TIM_MOE_ENABLE(&htim1)` 开启主输出。speed 0~100 直接对应 CCR。

### 方向控制 (TB6612 IN1/IN2)

| 功能 | 引脚 | 方向 |
|---|---|---|
| AIN1 (Motor A 方向1) | PE0 | 推挽输出 |
| AIN2 (Motor A 方向2) | PE1 | 推挽输出 |
| BIN1 (Motor B 方向1) | PE2 | 推挽输出 |
| BIN2 (Motor B 方向2) | PE3 | 推挽输出 |
| CIN1 (Motor C 方向1) | PB5 | 推挽输出 |
| CIN2 (Motor C 方向2) | PB6 | 推挽输出 |
| DIN1 (Motor D 方向1) | PB7 | 推挽输出 |
| DIN2 (Motor D 方向2) | PB12 | 推挽输出 |

### 待机控制

| 引脚 | 功能 | 备注 |
|---|---|---|
| PA10 | STBY | 0=全部停止, 1=使能 |

---

## 五、舵机 — 12× 270° Servo

### PWM 输出 (50Hz, PSC=23999, ARR=199)

| 舵机 | 腿 | 关节 | 引脚 | 定时器通道 | AF |
|---|----|---|---|---|-----|
| Servo 1 | Leg 1 | 外展 | PA0 | TIM2_CH1 | AF1 |
| Servo 2 | Leg 2 | 外展 | PA7 | TIM3_CH2 | AF2 |
| Servo 3 | Leg 3 | 外展 | PD15 | TIM4_CH4 | AF2 |
| Servo 4 | Leg 4 | 外展 | PD14 | TIM4_CH3 | AF2 |
| Servo 5 | Leg 1 | 大腿 | PB0 | TIM3_CH3 | AF2 |
| Servo 6 | Leg 2 | 大腿 | PB1 | TIM3_CH4 | AF2 |
| Servo 7 | Leg 3 | 大腿 | PD13 | TIM4_CH2 | AF2 |
| Servo 8 | Leg 4 | 大腿 | PD12 | TIM4_CH1 | AF2 |
| Servo 9 | Leg 1 | 小腿 | PA1 | TIM2_CH2 | AF1 |
| Servo 10 | Leg 2 | 小腿 | PA2 | TIM2_CH3 | AF1 |
| Servo 11 | Leg 3 | 小腿 | PA3 | TIM2_CH4 | AF1 |
| Servo 12 | Leg 4 | 小腿 | PB14 | TIM12_CH1 | AF2 |

### 舵机→腿→关节 映射速查

```
         关节 = 外展 / 大腿 / 小腿

Leg 1 (左前): Servo 1 / 5 / 9
Leg 2 (右前): Servo 2 / 6 / 10
Leg 3 (左后): Servo 3 / 7 / 11
Leg 4 (右后): Servo 4 / 8 / 12
```

### 云台舵机（2026-08-22 新增；PC8/PC9 被占用后换 PF8/PF9）

| 舵机 | 轴 | 引脚 | 定时器通道 | AF |
|---|----|---|---|-----|
| Gimbal 1 | 水平 pan | PF8 | TIM13_CH1 | AF9 |
| Gimbal 2 | 俯仰 tilt | PF9 | TIM14_CH1 | AF9 |

> TIM13/14 为通用定时器（无需 MOE）；PSC=23999/ARR=199 → 50Hz，与腿舵机同源配置。

### 定时器分配一览

| 定时器 | 通道 | 舵机 |
|---|---|---|
| TIM2 | CH1/CH2/CH3/CH4 | 1, 9, 10, 11 |
| TIM3 | CH2/CH3/CH4 | 2, 5, 6 |
| TIM4 | CH1/CH2/CH3/CH4 | 8, 7, 4, 3 |
| TIM12 | CH1 | 12 |

> TIM3_CH1 (PA6) 与 DCMI_PIXCLK 复用冲突，已禁用，不使用。

---

## 六、编码器 — 4× GMR 500PPR

| 编码器 | 腿 | A 相 (EXTI) | B 相 (方向) | 中断线 |
|---|----|---|---|---|
| ENC 1 | Leg 1 | PE7 | PE8 | EXTI7 → EXTI9_5_IRQn |
| ENC 2 | Leg 2 | PE9 | PE10 | EXTI9 → EXTI9_5_IRQn |
| ENC 3 | Leg 3 | PE11 | PE12 | EXTI11 → EXTI15_10_IRQn |
| ENC 4 | Leg 4 | PE13 | PE14 | EXTI13 → EXTI15_10_IRQn |

> A 相配置为 `GPIO_MODE_IT_RISING_FALLING`（双沿触发），B 相为 `GPIO_MODE_INPUT`。全部上拉。编码器在电机轴上（减速前），每圈 500PPR × 2(双沿) = 1000 个计数，经 1:28 减速后输出轴每圈 28000 计数。

| 中断 | 优先级 | 触发源 |
|---|---|---|
| EXTI9_5_IRQn | 6,0 | ENC1 (PE7) + ENC2 (PE9) |
| EXTI15_10_IRQn | 6,0 | ENC3 (PE11) + ENC4 (PE13) |

---

## 七、通信接口

### USART2 — IMU (WT9011G4K)

| 引脚 | 功能 | AF | 波特率 | 备注 |
|---|---|----|---|---|
| PD5 | USART2_TX | AF7 | 115200 | 发给 IMU（一般不用，上电环回自测用） |
| PD6 | USART2_RX | AF7 | 115200 | 接收 IMU 数据（11 字节/帧） |

| 中断 | 优先级 |
|---|---|
| USART2_IRQn | 5,0 |

> IMU 每 100ms 主动上报一帧（0x55+type+8data+checksum），HAL_UART_Receive_IT 逐字节接收。
> 接收链有双重保护：`HAL_UART_ErrorCallback` 自愈（上电时序噪声） + 主循环 1s 看门狗，详见 排错/IMU串口接收故障排查记。

### UART4 — 保留备用（暂未使用）

| 引脚 | 功能 | AF | 波特率 | 备注 |
|---|---|----|---|---|
| PC10 | UART4_TX | AF8 | 115200 | 预留 |
| PC11 | UART4_RX | AF8 | 115200 | 预留 |

| 中断 | 优先级 |
|---|---|
| UART4_IRQn | 0,0 |

### USART3 — 蓝牙 (HC-05)

| 引脚 | 功能 | AF | 波特率 | 备注 |
|---|---|----|---|---|
| PB10 | USART3_TX | AF7 | 115200 | DMA 发送 |
| PB11 | USART3_RX | AF7 | 115200 | 中断接收 |

| DMA | 流 | 方向 | 模式 | 优先级 |
|-----|----|---|---|---|
| DMA1_Stream1 | — | M→P (内存→外设) | NORMAL | LOW |

| 中断 | 优先级 |
|---|---|
| USART3_IRQn | 5,0 |
| DMA1_Stream1_IRQn | 0,0 |

> TX 使用 DMA 避免阻塞，`bluetooth_send()` 约 2.6ms 后台完成。RX 中断逐字节接收，拼 A5/5A 帧。

---

## 八、其他

### TIM5 — 32-bit 自由计数器

无外部引脚，仅作内部 32 位微秒级时间基准。PSC=0, ARR=2³²-1, 时钟=240MHz → 每个 tick ≈ 4.17ns。

> 当前未在代码中使用，预留。

### 系统时钟 & 晶振

| 引脚 | 功能 |
|---|---|
| PH0 | HSE OSC_IN (外部晶振，当前未用) |
| PH1 | HSE OSC_OUT |
| PC14 | LSE OSC32_IN (32.768kHz RTC 晶振) |
| PC15 | LSE OSC32_OUT |

> 当前使用 HSI 64MHz → PLL×60/4 = 480MHz。HSE 和 LSE 引脚预留但未使能。

---

## 九、硬件模块化分组（PCB 画板用）

> 实物由 5 个模块组成：3 块舵机驱动板（每板 4 路）+ 2 块 TB6612 电机驱动模块。
> 每个模块的 STM32 信号线、电源线分组列出，画板时按组走线。

### 模块 A：外展舵机驱动板（4 路）

| 板通道 | 舵机 | 腿 | STM32 信号 | 定时器 |
|---|---|-----|---|---|
| CH1 | Servo 1 | Leg1 左前 | PA0 | TIM2_CH1 |
| CH2 | Servo 2 | Leg2 右前 | PA7 | TIM3_CH2 |
| CH3 | Servo 3 | Leg3 左后 | PD15 | TIM4_CH4 |
| CH4 | Servo 4 | Leg4 右后 | PD14 | TIM4_CH3 |

| 电源 | 接法 |
|---|---|
| 板 VCC | 舵机电源（独立，如 7.4V 或 8.4V 锂电） |
| 板 GND | 舵机电源地 + 主控 GND 共地 |
| 板信号地 | 与 STM32 GND 直连 |

### 模块 B：大腿舵机驱动板（4 路）

| 板通道 | 舵机 | 腿 | STM32 信号 | 定时器 |
|---|---|-----|---|---|
| CH1 | Servo 5 | Leg1 左前 | PB0 | TIM3_CH3 |
| CH2 | Servo 6 | Leg2 右前 | PB1 | TIM3_CH4 |
| CH3 | Servo 7 | Leg3 左后 | PD13 | TIM4_CH2 |
| CH4 | Servo 8 | Leg4 右后 | PD12 | TIM4_CH1 |

### 模块 C：小腿舵机驱动板（4 路）

| 板通道 | 舵机 | 腿 | STM32 信号 | 定时器 |
|---|---|-----|---|---|
| CH1 | Servo 9 | Leg1 左前 | PA1 | TIM2_CH2 |
| CH2 | Servo 10 | Leg2 右前 | PA2 | TIM2_CH3 |
| CH3 | Servo 11 | Leg3 左后 | PA3 | TIM2_CH4 |
| CH4 | Servo 12 | Leg4 右后 | PB14 | TIM12_CH1 |

> 三块舵机板电源接线相同：板 VCC 接舵机电源，板 GND 与 STM32 GND 共地。
> 舵机电源必须独立于 STM32 电源，防止舵机启动电流拉垮主控。

### 模块 D：2 路 TB6612 电机驱动模块

| 板通道 | 电机 | 腿 | PWMA | AIN1 | AIN2 | 编码器A | 编码器B |
|---|---|-----|---|---|---|---|---|
| CH1 | Motor A | Leg1 左前 | PA8 (TIM1_CH1) | PE0 | PE1 | PE7 | PE8 |
| CH2 | Motor B | Leg2 右前 | PA9 (TIM1_CH2) | PE2 | PE3 | PE9 | PE10 |

**模块俯视图（丝印面朝上，常见 TB6612FNG 小板布局）：**

```
          ┌───────────────────────────┐
          │ PWMA □                 □ AO1 │
          │ AIN2 □                 □ AO2 │
          │ AIN1 □                 □ BO1 │
          │ STBY □                 □ BO2 │
          │ BIN1 □                 □ VM  │
          │ BIN2 □                 □ VCC │
          │ PWMB □                 □ GND │
          │  GND □                 □ GND │
          │  VCC □                 □ VM  │
          │   VM □                      │
          └───────────────────────────┘
           左侧=控制信号     右侧=电机输出+电源
```

> ⚠ 不同厂家的模块丝印顺序可能不同，接线前务必以实物丝印为准。

**与 STM32 的连线：**

```
  TB6612 模块           STM32
  ──────────            ─────────────
  PWMA ──────────────── PA8   (TIM1_CH1)
  AIN1 ──────────────── PE0
  AIN2 ──────────────── PE1
  STBY ──────────────── PA10
  BIN1 ──────────────── PE2
  BIN2 ──────────────── PE3
  PWMB ──────────────── PA9   (TIM1_CH2)
  VCC  ──────────────── 5V
  GND  ──────────────── 主控 GND + 电机电源地
  VM   ──────────────── 电机电源 (7.4V/12V)
  AO1/AO2 ───────────── Motor A 两根线 (正反无所谓)
  BO1/BO2 ───────────── Motor B 两根线
```

### 模块 E：4 路 TB6612 电机驱动模块

| 板通道 | 电机 | 腿 | PWMA | AIN1 | AIN2 | 编码器A | 编码器B |
|---|---|-----|---|---|---|---|---|
| CH1 | Motor C | Leg3 左后 | PB8 (TIM16_CH1) | PB5 | PB6 | PE11 | PE12 |
| CH2 | Motor D | Leg4 右后 | PB9 (TIM17_CH1) | PB7 | PB12 | PE13 | PE14 |
| CH3 | — | 空余 | — | — | — | — | — |
| CH4 | — | 空余 | — | — | — | — | — |

**模块俯视图（丝印面朝上，常见 4 路 TB6612 模块布局）：**

```
        ┌─────────────────────────────────┐
        │ PWMA □                       □ AO1 │
        │ AIN1 □                       □ AO2 │
        │ AIN2 □                       □ BO1 │
        │ PWMB □                       □ BO2 │
        │ BIN1 □                       □ CO1 │
        │ BIN2 □                       □ CO2 │
        │ PWMC □                       □ DO1 │
        │ CIN1 □                       □ DO2 │
        │ CIN2 □                       □ VM  │
        │ PWMD □                       □ VCC │
        │ DIN1 □                       □ GND │
        │ DIN2 □                       □ GND │
        │ STBY □                       □ VM  │
        │  GND □                            │
        │  VCC □                            │
        │   VM □                            │
        └─────────────────────────────────┘
          左侧=控制信号          右侧=电机输出+电源
```

> ⚠ 不同厂家丝印顺序可能不同，接线前以实物为准。

**与 STM32 的连线（只用 CH1/CH2，CH3/CH4 空余）：**

```
  TB6612 4路模块         STM32
  ─────────────          ─────────────
  PWMC ──────────────── PB8   (TIM16_CH1)
  CIN1 ──────────────── PB5
  CIN2 ──────────────── PB6
  PWMD ──────────────── PB9   (TIM17_CH1)
  DIN1 ──────────────── PB7
  DIN2 ──────────────── PB12
  STBY ──────────────── PA10 (与2路模块STBY并联)
  VCC  ──────────────── 5V
  GND  ──────────────── 主控 GND + 电机电源地
  VM   ──────────────── 电机电源
  CO1/CO2 ───────────── Motor C 两根线
  DO1/DO2 ───────────── Motor D 两根线
  (PWMA/AIN1/AIN2/PWMB/BIN1/BIN2 空余不接)
```

> 编码器（GMR 500PPR）装在电机轴上，A/B 相直接引到 STM32 的 EXTI 引脚：
> PE7/PE9/PE11/PE13 是 EXTI 双沿计数脚，PE8/PE10/PE12/PE14 是方向判断脚。
> 画板时编码器信号线和电机 PWM 线分开走，避免 PWM 干扰计数。

### 共享信号

| 信号 | 引脚 | 接到哪 |
|---|---|---|
| STBY | PA10 | 两个 TB6612 模块的 STBY 并联 |
| 蓝牙 TX | PB10 | HC-05 RXD |
| 蓝牙 RX | PB11 | HC-05 TXD |

> 两个 TB6612 的 STBY 可以并联接 PA10（当前代码 `Motor_Init()` 只控制一个 STBY 引脚）。
> 如果模块 STBY 独立，则 2 路模块接 PA10，4 路模块需要另配 GPIO（当前未分配）。

### PCB 布线建议

```
                    ┌─────────┐
  舵机电源 ──12V───→│ 模块A 外展板 │──→ Servo 1~4
                    │ 模块B 大腿板 │──→ Servo 5~8
  主控电源 ──5V───→ │ 模块C 小腿板 │──→ Servo 9~12
                    └─────────┘
  电机电源 ──12V──→ 模块D (2路) ──→ Motor A/B
                   模块E (4路) ──→ Motor C/D
                    └─────────┘
  STM32 GND ═══════ 所有模块 GND 共地
```

---

## 十、引脚按端口汇总

```
PORTA:
  PA0   TIM2_CH1    Servo 1 (Leg1 外展)
  PA1   TIM2_CH2    Servo 9 (Leg1 小腿)
  PA2   TIM2_CH3    Servo 10 (Leg2 小腿)
  PA3   TIM2_CH4    Servo 11 (Leg3 小腿)
  PA4   DCMI_HSYNC  摄像头行同步
  PA6   DCMI_PIXCLK 摄像头像素时钟
  PA7   TIM3_CH2    Servo 2 (Leg2 外展)
  PA8   TIM1_CH1    Motor A PWM
  PA9   TIM1_CH2    Motor B PWM
  PA10  STBY        电机待机控制

PORTB:
  PB0   TIM3_CH3    Servo 5 (Leg1 大腿)
  PB1   TIM3_CH4    Servo 6 (Leg2 大腿)
  PB5   CIN1        Motor C 方向1
  PB6   CIN2        Motor C 方向2
  PB7   DIN1        Motor D 方向1
  PB8   TIM16_CH1   Motor C PWM
  PB9   TIM17_CH1   Motor D PWM
  PB10  USART3_TX   蓝牙发送
  PB11  USART3_RX   蓝牙接收
  PB12  DIN2        Motor D 方向2
  PB14  TIM12_CH1   Servo 12 (Leg4 小腿)

PORTC:
  PC6   (空闲)      原摄像头 D0
  PC7   (空闲)      原摄像头 D1
  PC8   (空闲)
  PC9   (空闲)
  PC14  OSC32_IN    RTC 晶振 (预留)
  PC15  OSC32_OUT   RTC 晶振 (预留)

PORTD:
  PD3   DCMI_D5     摄像头数据 bit5
  PD5   USART2_TX   IMU 发送
  PD6   USART2_RX   IMU 接收
  PD12  TIM4_CH1    Servo 8 (Leg4 大腿)
  PD13  TIM4_CH2    Servo 7 (Leg3 大腿)
  PD14  TIM4_CH3    Servo 4 (Leg4 外展)
  PD15  TIM4_CH4    Servo 3 (Leg3 外展)

PORTE:
  PE0   AIN1        Motor A 方向1
  PE1   AIN2        Motor A 方向2
  PE2   BIN1        Motor B 方向1
  PE3   BIN2        Motor B 方向2
  PE4   DCMI_D4     摄像头数据 bit4
  PE5   DCMI_D6     摄像头数据 bit6
  PE6   DCMI_D7     摄像头数据 bit7
  PE7   ENC1_A      编码器1 A相 (EXTI7)
  PE8   ENC1_B      编码器1 B相
  PE9   ENC2_A      编码器2 A相 (EXTI9)
  PE10  ENC2_B      编码器2 B相
  PE11  ENC3_A      编码器3 A相 (EXTI11)
  PE12  ENC3_B      编码器3 B相
  PE13  ENC4_A      编码器4 A相 (EXTI13)
  PE14  ENC4_B      编码器4 B相

PORTF:
  PF8   TIM13_CH1   云台舵机 水平 pan
  PF9   TIM14_CH1   云台舵机 俯仰 tilt
  PF13  (空闲)      原摄像头 PWDN
  PF14  (空闲)      原 SCCB_SCL
  PF15  (空闲)      原 SCCB_SDA

PORTG:
  PG8   SPI6_NSS    LCD 片选
  PG9   DCMI_VSYNC  摄像头帧同步
  PG10  DCMI_D2     摄像头数据 bit2
  PG11  DCMI_D3     摄像头数据 bit3
  PG12  LCD_BL      LCD 背光
  PG13  SPI6_SCK    LCD 时钟
  PG14  SPI6_MOSI   LCD 数据
  PG15  LCD_DC      LCD 数据/命令

PORTH:
  PH0   OSC_IN      HSE 晶振 (预留)
  PH1   OSC_OUT     HSE 晶振 (预留)
```

---

## 十一、中断优先级总表

| 优先级 (Pre,Sub) | 中断 | 用途 |
|---|---|---|
| 0,0 | DCMI_IRQn | 摄像头帧完成 |
| 0,0 | DMA2_Stream7_IRQn | DCMI DMA 传输 |
| 0,0 | DMA1_Stream1_IRQn | 蓝牙 DMA 发送完成 |
| 5,0 | USART2_IRQn | IMU 数据接收 |
| 5,0 | USART3_IRQn | 蓝牙数据接收 |
| 6,0 | EXTI9_5_IRQn | 编码器 1+2 |
| 6,0 | EXTI15_10_IRQn | 编码器 3+4 |

> 摄像头 DMA 优先级最高 (0,0)，保证视频流不丢帧。编码器优先级最低 (6,0)，漏几个计数不影响整体。

---

## 十二、未使用引脚 (可供扩展)

以下端口引脚在 144 脚封装中完全空闲：

| 端口 | 空闲引脚数 | 可用引脚 |
|---|---|---|
| PA | 7 | PA4, PA5, PA6, PA11, PA12, PA15（PA13/PA14 留调试器） |
| PB | 5 | PB2, PB3, PB4, PB13, PB15 |
| PC | 8 | PC0~PC7, PC10~PC13 (部分含 JTAG；PC8/PC9 已用于云台) |
| PD | 7 | PD0~PD4, PD7~PD11 |
| PE | 4 | PE4~PE6, PE15 |
| PF | 11 | PF0~PF7, PF10~PF15 (部分含 JTAG/BOOT；PF8/PF9 已用于云台) |
| PG | 13 | PG0~PG15 (部分) |
| PH | 13 | PH2~PH15 (部分含 JTAG) |

> 2026-08-22 摄像头/LCD 移除后释放：PA4/PA6、PC6/PC7、PD3、PE4~PE6、PG8~PG15、PF13~PF15。

> ⚠ PA13( JTMS-SWDIO), PA14( JTCK-SWCLK) 需保留给调试器。如引脚不够，可释放这些 JTAG 脚但需注意 SWD 仍要两根线。

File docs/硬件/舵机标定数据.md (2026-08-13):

# 舵机标定数据

> 四腿自然站立、身体水平时，每个舵机的度数。
> zero_deg：站姿角度，蓝牙调到站稳时的读数。
> dir：角度+10°，和几何正方向一致=1.0，反了=-1.0。

| 关节 | 几何正方向 |
|---|---|
| 外展 | 腿往外摆 |
| 大腿 | 腿往前摆 |
| 小腿 | 膝弯曲 |

---

| 腿 | 关节 | 舵机(引脚) | zero_deg | dir |
|----|---|---|---|-----|
| Leg1 左前 | 外展 | 1 (PA0) |98 |1.0 |
| | 大腿 | 5 (PB0) |240 |-1.0 |
| | 小腿 | 9 (PA1) |153 |1.0 |
| Leg2 右前 | 外展 | 2 (PA7) |94 |-1.0 |
| | 大腿 | 6 (PB1) |35 |1.0 |
| | 小腿 | 10 (PA2) |74 |-1.0 |
| Leg3 左后 | 外展 | 3 (PD15) |50 |-1.0 |
| | 大腿 | 7 (PD13) |135 |-1.0 |
| | 小腿 | 11 (PA3) |220 |1.0 |
| Leg4 右后 | 外展 | 4 (PD14) |150 |1.0 |
| | 大腿 | 8 (PD12) |200 | 1.0|
| | 小腿 | 12 (PB14) |30 |-1.0 |

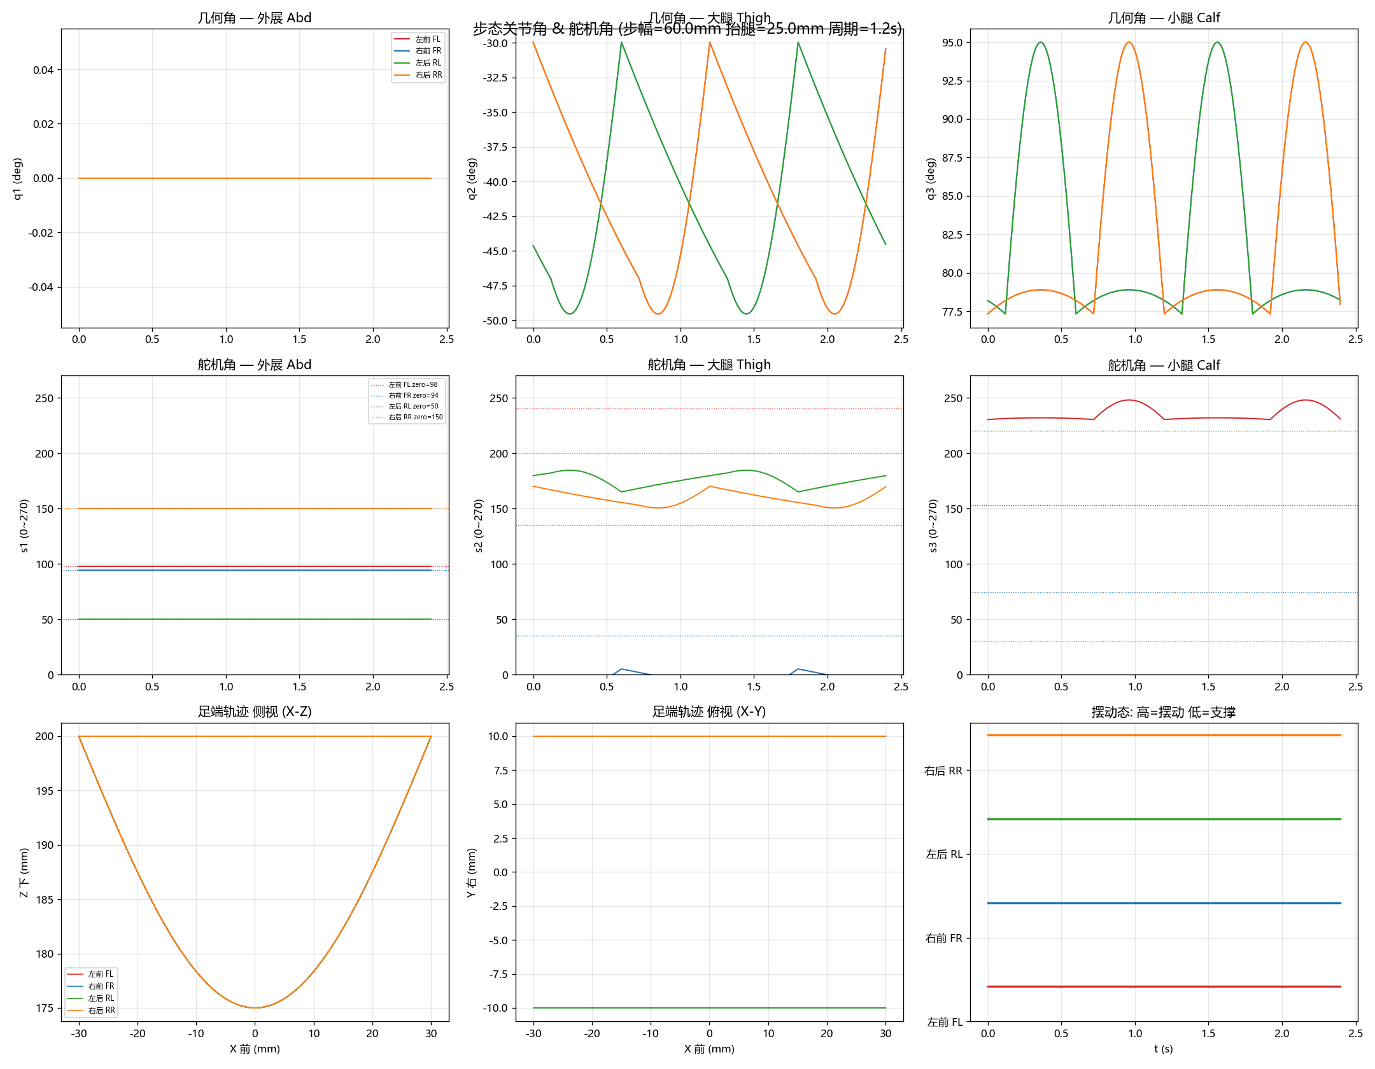
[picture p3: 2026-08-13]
tools/angle_check.png

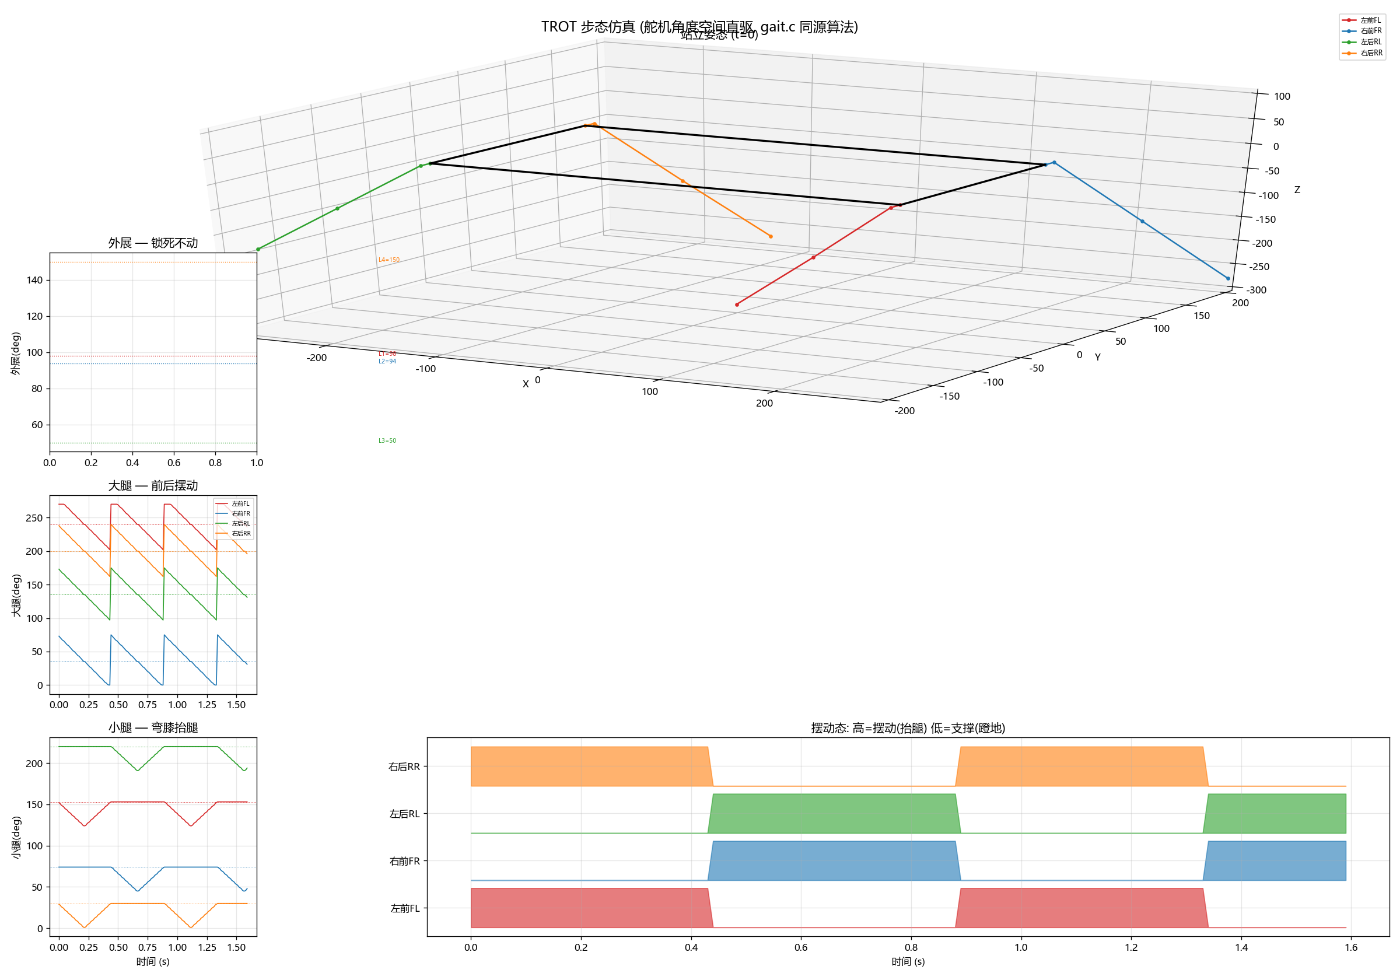
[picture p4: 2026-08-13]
tools/gait_sim.png

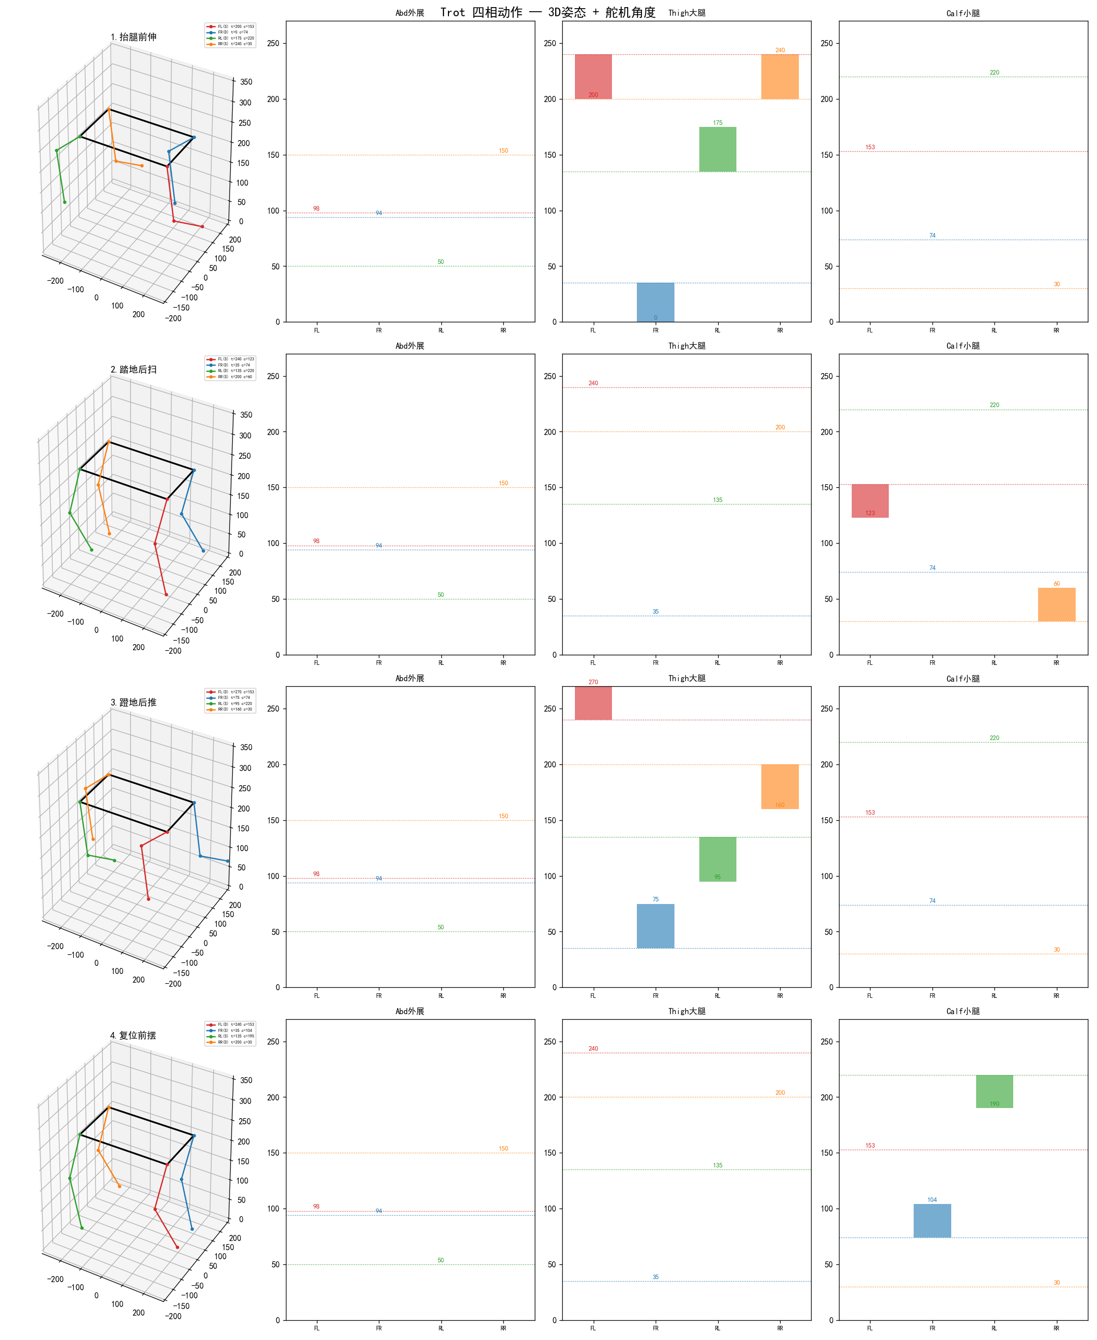
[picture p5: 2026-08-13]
tools/trot_4phase_detail.png

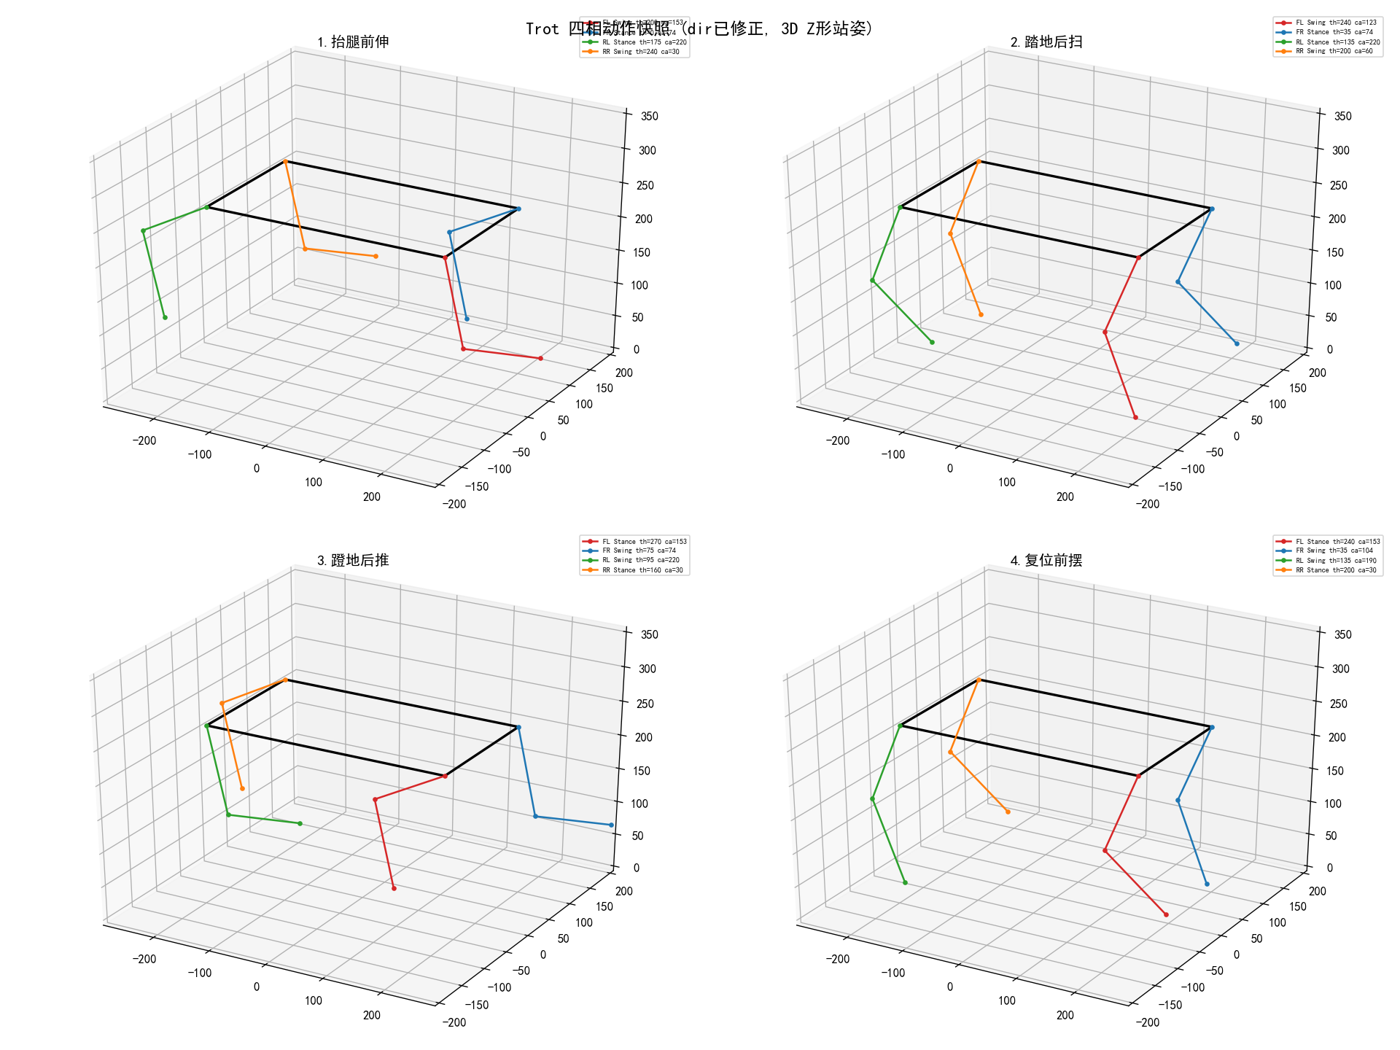
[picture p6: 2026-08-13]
tools/trot_4phase.png

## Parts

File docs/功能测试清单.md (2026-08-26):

# 四足机器人功能测试清单 v2.0

> 适用固件：蓝牙协议 v6.5 对应版本。
> 测试方式：手机/PC 蓝牙串口助手（115200）发命令，对照回显 + 观察动作。
> **测试纪律**：每一步都先看回显、再看动作；异常立即 `S`；有任何与预期不符 → 记录现象后继续下一项，最后统一汇报。

---

## 测试前准备（10 分钟）

- [ ] 接线复查：12 舵机、4 电机、IMU（TX→PD6，**115200**）、HC-05（115200）
- [ ] **Clean 后编译烧录**（工程删过/加过文件，必须 Clean）
- [ ] 蓝牙已连，串口助手能看到 `READY`
- [ ] 机器人放**平地**，四周 1m 净空
- [ ] 测试材料：一本 2~3cm 厚的书（越障用）、一块长木板 + 垫高物（做 10° 斜坡用）

---

## 阶段 A：上电自检（5 分钟，不发任何命令）

| 步骤 | 预期 |
|---|---|
| 上电瞬间 | 12 舵机无乱动 |
| 随后 | 4 个外展舵机**间隔约 100ms 逐个**锁到 95 / 99 / 50 / 150° |
| 大腿/小腿 | 松弛可手掰 |
| 串口 | 收到 `READY`；**无** IMU 数据流（I 默认关） |
| 电机 | 不转 |

---

## 阶段 B：IMU 上报（10 分钟）

| 步骤 | 命令 | 预期回显/现象 |
|---|---|---|
| 开启上报 | `I` | `IMU:ON`，随后每 100ms 一行 `R,x,P,y,Y,z,520`（如 `R,-12,P,34,Y,1579,520`） |
| 诊断行 | 按 `I` 后等 1 秒 | 一行 `DBG2:CR1=... raw=N frames=N` |
| 平放读数 | — | P 值 ÷10 ≈ 0±3° |
| 手动前倾 | — | P 值往**正**走 |
| 手动后倾 | — | P 值往**负**走 |
| 左右滚 | — | R 值变化 |
| 关闭上报 | `I` | `IMU:OFF`，数据流停 |
| 上电时序验证 | IMU 线**保持接好** → 整机断电重启 → `I` | 直接有数据流（不需要重插线）——验证 ErrorCallback+看门狗双保险 |
| 断线告警 | 拔 IMU 线 | 约 5s 后每 2s 一行 `IMU:NO DATA raw=N frames=N`；插回自动恢复 |

---

## 阶段 C：姿态系统（30 分钟）

### C1 G — 狗高站姿

| 命令 | 预期 |
|---|---|
| `G` | 回 `STAND...` + `OK:STAND`；腿平滑升/降到 280mm 狗姿态（前后正常膝） |
| `L` → `K` | **升站慢速**：约 1.5s 平滑升起（比下降慢，108mm 大轮负载下不卡顿、无滋滋声） |

### C2 K — 前顶高站姿

| 命令 | 预期 |
|---|---|
| `K` | 回 `KNEE` → `FLIP`；前腿足端先往前滚伸直到腿伸直、再收回（约 3s） |
| 目测 | 前腿大腿前摆、**膝盖顶在身体前方**、膝轴离地约 192mm（108mm 轮径基准） |

### C3 L — 前顶低趴

| 命令 | 预期 |
|---|---|
| `L` | 回 `LOW`；**无 FLIP**（同分支直接下降），趴到 191mm |
| 目测 | 四足 ±129.5 对称展开，**大腿≈平行地面、小腿垂直地面**（视觉姿态），膝高(几何) 180mm（实际离地再 +54mm），四轮着地 |

### C4 P — 后顶高站姿

| 命令 | 预期 |
|---|---|
| `P` | 回 `REARH` → `FLIP`；前后腿**同时**翻膝（约 3s），升到 280 |
| 目测 | 后腿大腿前摆、膝盖顶在身体前下方 |

### C5 M — 后顶低趴

| 命令 | 预期 |
|---|---|
| `M` | 回 `REAR`；**无 FLIP**，直接趴到 240 |
| 目测 | 前腿狗腿、后腿膝盖收进车身下，四膝离地 |

### C6 切换矩阵（全组合走一遍）

按序执行，每步确认站高/膝分支：

```
G → K → L → M → P → H → L → K → M → G
```

**规律**：K↔L、M↔P 无 FLIP（直接升降）；其余组合先 `FLIP`（约 3s）再升降；任何切换膝不磕地、轮不侧铲。

### C7 翻膝专项观察

- [ ] `FLIP` 回显在按下约 0.8s 后出现，总时长约 3s
- [ ] 全程膝离地 ≥110mm（低趴态除外）
- [ ] 翻完后自动继续升降

### C8 坐姿 O（2026-08-21 新增）

| 命令 | 预期 |
|---|---|
| `G` → `O` | 回 `FLIP`（后腿翻膝约 3s）→ `SIT`；前腿竖直伸直、后腿反折深蹲、车身自然抬头约 10°，狗坐造型 |
| `M` → `O` | 后腿已反折：**无 FLIP** 直接坐 |
| `O` → `G` | 平滑回狗高站姿 |
| 坐姿下 `R` | 四轮前进（坐姿开车） |

### C9 云台（2026-08-22 新增）

| 命令 | 预期 |
|---|---|
| 上电 | 云台自动回**正对前方**（水平 90 / 俯仰 120） |
| `G:60:120` | 回 `GM:60,120`；水平右转 30°（<90 往右），俯仰不动 |
| `G:120:120` | 水平左转 30°（>90 往左） |
| `G:90:75` | 俯仰向下 45°（机械限位，<75 会被钳在 75） |
| `G:90:180` | 俯仰向上到顶 |
| `G:90:30` | 俯仰命令 30°（低于限位）→ 实际停在 75°，回显 `GM:90,75` |
| 行走中发 `G:90:120` | 云台动作，腿行走不受影响 |

### C10 站立自稳（2026-08-23 新增，H/K 高站姿）

前置：平地、`G` 或 `K` 站姿（放平地并扶稳）。

| 命令 | 预期 |
|---|---|
| `L:1`（未标定） | 回 `LV:NOCAL`，腿不动 |
| `Z` → 等 2s | 回 `CAL:OK`（自稳零偏已存） |
| `L:1` | 回 `LV:ON`，平地上腿不动（零偏正确） |
| 前轮下垫 **30mm** 木块 | ~1s 内前腿伸长/后腿缩短，身体自动回平（4.5° 倾角） |
| 前轮下垫 **50mm** | 身体回平（7.5°，接近前腿伸直极限）；再垫高身体保留剩余倾斜、不崩 |
| 右侧两轮垫 **40mm** | 右腿伸长/左腿缩短，身体回平（滚转 12.5°）；**若方向相反 → 记录并反馈（roll 符号待实测）** |
| 垫块撤走 | 身体回平（dz 归零） |
| `T` 行走中 | 自稳不叠加（步态正常）；`S` 停后回站立自动恢复自稳 |
| `C` → `U` | 收纳/站起过程中自稳不叠加，站起完成后恢复 |
| `K` 姿态重复垫块测试 | 前顶高站姿同样回平（需先 `Z` 标定 K） |
| `L:0` | 回 `LV:OFF`，身体停在当前姿态不再修正 |
| `W` 用过后发 `L:0` | 总开关：W 残留的自稳跟随也一并关闭（腿不再自动调平，直到再发 L:1 或 S/经典V） |
| 重启 | 自稳开关回默认关（不记忆） |
| 平地轻推机身（<1° 晃动） | 腿**不动**（±1° 死区生效）；手压机身 >2° 才响应 |
| 垫 30mm 块后回平 | 回平过程无过冲震荡（死区不引入阶跃） |

### C11 V 模式1 无倾斜驱动（2026-08-23 新增，第二套轮盘）

前置：平地、`G` 高站姿、`Z` 标定过 H。

| 命令 | 预期 |
|---|---|
| `V:30:0:1` | 四轮前进 30%；**起步不低头**（无倾斜补偿）；回平后身体水平 |
| `V:0:30:1` | 原地右转；**不压弯**（无侧倾补偿） |
| 行驶中前轮上小坡/过坎 | 身体自动保持水平（自稳跟随，和站立自稳同效果） |
| `V:-30:0:1` | 后退，同样无倾斜 |
| `V:0:0:1` | 渐停，身体保持水平（自稳仍在） |
| `V:30:0`（无第三参） | 回经典模式：起步**有**低头倾斜补偿 |
| `K` 姿态下发 `V:30:0:1` | 回 `FLIP` 自动翻回 H（约 3s），翻完前轮子不动；翻完继续前进 |
| `L` 低趴下发 `V:30:0:1` | 同上：先翻膝回 H 再走 |
| `S` 停止后发 `V:30:0:1` | 直接走（H 已是正常膝，无 FLIP） |
| 未 `Z` 标定发 `V:30:0:1` | 正常驱动，但自稳不生效（腿不动）；标定后恢复 |
| `H:230` | 回 `HIGH:230`；从 280 平滑蹲到 230（~1s 渐变） |
| `H:230` 后前轮垫高 70mm（≈10.5°） | 自稳回平（280 站高做不到 10.5°，230 站高 23° 以内可回平） |
| `H:230` 下 `V:20:0:1` 上真坡（≤23°） | 车身全程保持水平；若坡 >23° 身体保留剩余倾斜（钳位不崩） |
| 行驶中发 `H:230` | 边滚边平滑蹲下，自稳不掉线 |
| 回平地发 `H` | 平滑站回 280，回 `HIGH` |
| `H:100`（非法值） | 回 `HIGH:230`（落缺省 230） |

---

## 阶段 D：步态（20 分钟）

### D1 T — 连续 Trot

| 命令 | 预期 |
|---|---|
| `G` → `T` | 回 `TROT`；平滑渐入后持续走（1.2s/周期、步幅 60mm）+ **四轮 10% 助走**，**无左右摇摆**，直线前进 |
| `G` → `T:-1` | 回 `TROTB`；**倒着走**（负步幅 + 四轮 10% 反向助走），直线后退 |
| `G` | 平滑回站姿停住，**轮子同步停** |

### D2 A — 单步调试

| 命令 | 预期 |
|---|---|
| `G` → `A`×4 | 回 `PH:0` → `PH:90` → `PH:180` → `PH:270`，每次停在对应相位 |

### D3 W — 越障抬腿（原地版，2026-08-24 改）

前置：`G` 高站姿 + `Z` 标定过（自稳跟随防翘板）。

| 命令 | 预期 |
|---|---|
| `W` | 回 `CLIMB`；对角交替**原地**抬腿 50mm（足端不前移、**四轮不动**；前后腿抬升高度一致） |
| 放地上持续看 10s | **机身不倾斜**、两条摆动腿都离地、**不原地转圈**（自稳 + 重心左移 15mm 补偿生效） |
| 还往右倾 | `W:25` 加大左移重测；往左倾了则 `W:5` 回退（±40 范围） |
| 还在往右转 | `W:25` 加大左移（右转=右侧偏重的标志） |
| `W` 中发 `V:20:0:1` | 无倾斜轮盘前进，边抬腿边走（轮子由轮盘控制），机身保持水平 |
| `V:0:0:1` | 轮停、腿继续原地抬 |
| `S` → `G` | 停轮、腿回站姿 |
| 边界：`L` → `W` | 自动先 `FLIP` 回正常膝再开抬 |
| `W` → `T` | 退出越障回纯行走（恢复步幅 60/抬腿 25，无轮） |

### D4 E — 转圈动作

| 命令 | 预期 |
|---|---|
| `G` → `E` | 回 `SWAY:1`；顺时针原地转圈 |
| `E:0` | 回 `SWAY:-1`；逆时针，速度相当 |
| `G` | 停止 |

### D5 边界记录（无需修）

| 命令 | 现象（记录即可） |
|---|---|
| `L` → `T` | 低趴行走，小腿可能钳位、动作怪异——属预期外用法，正式使用先 `G` |

---

## 阶段 E：轮式控制（10 分钟）

| 命令 | 预期回显/现象 |
|---|---|
| `G` → `R` | `ROLL`，四轮 30% 前进直线 |
| `B` | `BACK`，后退 |
| `S` | `STOP`，立即全停 |
| `M0:50:1` | `MA:50:1`，电机 A 50% 正转 |
| `M0:0` | `MA:0:1`，电机 A 停 |
| `M2:100` | `MC:100:1`，电机 C 100% 正转（方向缺省验证） |
| **`M` 单独发** | `REAR` 并执行后顶低趴（**姿态命令不被吞**——M 冲突修复验证） |
| `G` | 回狗高站姿 |
| `L` → `R` → `G` | 滚动中切姿态：轮子不停（G 不碰电机），腿平滑升起——正常行为 |

---

## 阶段 F：坡度自适应（已删除）

> 2026-08-23 坡度自适应层已从固件删除（未实测、与站立自稳职责重叠）。
> 相关能力由 **C10 站立自稳**（站立回平）与 **C11 V模式1 无倾斜驱动**（行驶自稳跟随）覆盖。

---

## 阶段 G：修正命令（5 分钟）

| 命令 | 预期 |
|---|---|
| `X:25` | 回 `XSH:25`；身体后坐，观察与默认 15 的差异 |
| `X:15` | 恢复默认 |

---

## 阶段 H：异常边界抽查（10 分钟）

- [ ] 翻膝进行中（`FLIP` 后 3s 内）按 `G`：翻膝继续、完成后按新目标执行，无乱动作
- [ ] 翻膝进行中按 `S`：电机停，腿部不受影响
- [ ] 发未知命令（如 `C`）：回 `UNK:C`
- [ ] 任何动作出现"滋滋"堵转声 → 立即 `S` 断电，记下是哪个关节

---

## 阶段 I：摇杆驱动与倾斜平衡（30 分钟，新功能）

> 先测编码器（I1），编码器通了再测倾斜（I2~I5）——倾斜的"到速回平"依赖编码器平台期判定。

### I1 编码器转速上报

| 步骤 | 命令 | 预期 |
|---|---|---|
| 开启 | `J` | 回 `J:ON`，之后每 100ms 一行 `E,e0,e1,e2,e3,520`（静止时全 0） |
| 四轮正转 | `R` | 四个值一起变正，约 **108 RPM**（30% 占空比 × 满速 360） |
| 停 | `S` | 归零 |
| 四轮反转 | `B` | 四个值一起变负 |
| 停 | `S` | 归零 |
| 单轮核对 | `M0:50:1` | **只有 e0 变**，约 **180 RPM**（实测） |
| | `M1:50:1` / `M2:50:1` / `M3:50:1` | 分别只有 e1 / e2 / e3 变 → 通道映射确认 |
| 关闭 | `J` | 回 `J:OFF` |

> ⚠️ 若电机转动但数值全 0 → 编码器没通（CubeMX EXTI 配置/接线问题），**先修好再往下测**。

### I2 V 前进 + 起步低头

| 步骤 | 命令 | 预期 |
|---|---|---|
| 站好 | `G` | 狗高站姿 |
| 起步 | `V:30:0` | **无回显**（正常）；约 0.3s 渐快至 30% 占空比直线前进（V 值=占空比%，1:1）；起步瞬间平台**低头**（前低后高，最多约 4.5°） |
| 到速 | 保持 `V:30:0` | 速度稳定后约 0.3s 内平台**自动回平** |
| 持续 | — | 匀速直线前进，车身平稳 |

### I3 V 渐停 + 刹车抬头

| 步骤 | 命令 | 预期 |
|---|---|---|
| 减速 | `V:0:0` | 约 0.5s 内渐停（不是急刹）；减速期间平台**抬头**（前高后低）；停稳后完全回平 |

### I4 V 后退

| 步骤 | 命令 | 预期 |
|---|---|---|
| 后退 | `V:-20:0` | 后退；起步**抬头**补偿（车身前栽的反向补偿）；`V:0:0` 渐停 |

### I5 转弯压弯

| 步骤 | 命令 | 预期 |
|---|---|---|
| 原地右转 | `V:0:40` | 原地右转（俯视顺时针）+ 平台**右倾**（左低右高，最多约 2.7°）；`V:0:0` 停 + 回平 |
| 原地左转 | `V:0:-40` | 对称：左转 + 左倾 |
| 混合 | `V:30:15` | 前进 + 右转，边转边压弯 |
| 回中 | `V:0:0` | 渐停回平 |

### I6 方向核对（重点，不对就报告）

- [ ] `V:30:0` 是**前进**（不是后退）
- [ ] `V:0:40` 是**右转**（俯视顺时针，不是左转）
- [ ] 若方向反 → 记录现象，改一行代码即可

### I6.5 按键驾驶新页（D 模式1，2026-08-25 新增）

前置：`G` 高站姿 + `Z` 标定过（自稳部分才生效）。

| 命令 | 预期 |
|---|---|
| `D:0:30:1` | 前进 30%，**起步不低头**（无倾斜补偿） |
| `D:1:30:1` | 后退 30%，无倾斜 |
| `D:2:30:1` | 左转：左轮 20% / 右轮 30%（小差速弧线）；**不压弯** |
| `D:3:30:1` | 右转：左 30% / 右 20% |
| `L:1` 开自稳后 `D:0:30:1` 上缓坡/过坎 | 行驶中身体自动调平（自稳跟全局开关） |
| `L:0` 关自稳后 `D:0:30:1` | 纯驾驶，腿不动（自稳不自动开，与 V 模式1 不同） |
| `S` | 停轮 |
| `U:1` ×2 | 回 `SPD:35` → `SPD:40`；再发 `D:0::1`（不带速度）按 40 前进 |
| 行驶中发 `U:0` | 回 `SPD:35`；**立即生效**（车速渐变到新档，方向不变） |
| `U:1` ×10 | 钳在 `SPD:50`；`U:0` ×10 钳在 `SPD:10` |
| 经典 `D:0:30`（无第三参） | 回经典模式：前进 + 低头 10mm 全程保持 |

### I6.8 单腿抬腿（N:，2026-08-25 新增）

前置：`G` 高站姿 + `Z` 标定 + `L:1` 开自稳。

| 命令 | 预期 |
|---|---|
| `N:0:1` | 回 `LG:0,1`；左前腿 0.8s 平滑抬起 50mm 并前伸 80mm，悬空保持；身体基本不倾（三腿支撑 + 自稳） |
| `N:1:1`（右前） | 抬起时**支撑腿自动左移**（重心转移 15mm），机身不往右倒——重点验证 |
| `N:0:0` | 回 `LG:0,0`；1.2s 慢慢放下，足端停在前伸位着地（不回原位） |
| `N:1:1` 抬起中 → `N:2:1` | 回 `LG:BUSY`（互斥：FR 在空中） |
| `N:1:1` → `N:1:0` 落地后 → `N:2:1` | **不 BUSY**：FR 落地即释放，RL 立即能抬（前伸记忆模式） |
| 四腿依次抬放一轮 | 四足全部前伸 80mm 姿态（身体不位移）；期间每腿落地后即可抬下一条 |
| 前伸的腿再按抬（`N:0:1` 第二次） | 原地抬起（不追加前伸，80mm 上限） |
| 四腿前伸后发 `G` | 四足全部滚回站立位（前伸记忆清零） |
| 抬起中立即 `N:1:0` | 中途转放下，无跳变（平滑反向） |
| `N:3:1`（右后） | 右后腿抬起 50×80（后腿舵机余量验证） |
| `L:1` 开着，前轮垫 30mm + `N:0:1` | 抬 FL 过程中其余三腿自稳调平，机身保持水平 |
| `N:2:1` 悬空时发 `V:15:0:1` | 其余三轮行进，空中的 RL 保持悬空，机身自稳 |
| `V:0:0` → `N:2:0` | 放下后继续走 |
| 悬空时发 `G` | 空中腿立即收回站立位 |
| `T` 行走中发 `N:0:1` | 回 `LG:NO`（trot 不可用） |
| 裸 `N` | 仍是舵机校准退出（`CANCEL`），与 N: 不冲突 |

### I6.9 上台阶双腿抬（N:4/N:5，2026-08-25 新增）

前置：`G` 高站姿；平地先测。

| 命令 | 预期 |
|---|---|
| `N:4:1` | 回 `LG:4,1`；前双腿 50mm 直抬，**两条腿同时抬起**，到位悬空保持 |
| 按住期间重复 `N:4:1` | 回 `LG:4,1` 确认，不重置相位 |
| `N:4:0` | 回 `LG:4,0`；前双腿同时放下（1.2s） |
| `N:5:1` → `N:5:0` | 后双腿同样（RR 大腿 ~259° 验证） |
| 双腿抬起时 `L:1` 自稳 | **不叠加**（台阶让位）：支撑腿不动，身体可自然俯仰 |
| 前腿抬着发 `V:20:0:1` | 后轮驱动前进，抬着的前腿保持悬空 |
| 真台阶（≤40mm）：前轮顶台阶 → `N:4:1` + `V:20:0:1` → 前轮滚上 → `N:4:0` | 前腿放下撑住台面；再 `N:5:1` + 前推 → 后轮滚上 → `N:5:0` 完成 |
| 双腿模式中 `N:0:1` | 回 `LG:BUSY`（互斥） |
| 抬着时发 `G` | 立即收回站立位 |

### I7 交互边界

| 场景 | 预期 |
|---|---|
| V 行驶中按 `S` | 立即停 + 回平（急停，不走斜坡） |
| V 行驶中按 `R` | R 接管（30% 前进），倾斜归零 |
| V 行驶中按 `G` | 腿回站姿，轮子继续滚（G 不碰电机，正常行为） |
| `L` 低趴下发 `V:30:0` | 低趴姿态摇杆驱动（经典倾斜模式） |

### I8 手感调优（测试后把感觉发我）

| 感觉 | 改哪个 |
|---|---|
| 起步太猛/太肉 | 斜坡速率（当前 0.5s 到满速） |
| 倾斜太大/太小 | k_pitch（当前 15mm 满量程） |
| 压弯太大/太小 | k_roll（当前 10mm 满量程） |
| 倾斜收放太突兀 | tilt_slew（当前 300ms 过渡） |

> ⚠️ 2026-08-20 换 108mm 大轮后，同占空比实际车速约 +67%（50% 占空比 ≈1.0 m/s），起步/刹车手感需重测；太快可调 D 默认速度。

---

## 阶段 J：方向按键（20 分钟，固定倾斜版）

| 步骤 | 命令 | 预期 |
|---|---|---|
| 前进 | `D:0:30` | 回 `DRV:0:30`；30% 占空比前进，**全程保持低头 10mm**（不到速回平） |
| 停止 | `S` | 急停 + **立即回平**（这是唯一回平时机） |
| 后退 | `D:1:30` | 后退，**全程保持抬头 10mm** |
| 停止 | `S` | 回平 |
| 左前 | `D:2:30` | 前进+左弧线（左轮约4%/右轮约40%，弧线明显），**左边低**（左倾 10mm + 低头 6mm）全程保持 |
| 右前 | `D:3:30` | 前进+右弧线，**右边低**（右倾 10mm）全程保持 |
| 停止 | `S` | 回平 |
| 覆盖关系 | `D:0:30` → `V:30:0` → `D:3:30` | V 与 D 互斥，谁最后按下谁接管（摇杆代码保留） |

> 注意：D 按键的倾斜**不到速回平**——行驶全程保持，`S` 才平。与 V 的"到速自动回平"是两种行为，按需用。

---

## 阶段 K：收纳与站起（15 分钟）

| 步骤 | 命令 | 预期 |
|---|---|---|
| 收纳 | `G` 站好后 → `C` | 回 `PARK`；**慢速缓降约 2~3s** 到 72mm 贴地趴：四腿伸直外展 ±297、膝高约 67mm、肚皮离地约 **53mm**（108mm 大轮抬高车身） |
| 断电落地 | **断电** | 肚皮再落 ~53mm（落差比旧轮大 21.5mm），**重点听砸落力度**；轮子保持外伸，无关节折进身下 |
| 上电 | 上电（不发命令） | 外展锁定不扭腿（q1≈0 兼容）；大腿/小腿松弛 |
| 规划站起 | `U`（上电后**直接可用**，不再 NOT PARK） | 回 `RISE`；**指令角先同步趴姿**（不上扫腿）→ 单段 3.5s **先顶升后收腿**到前顶低趴 191（低处足端保持外伸，随站高上升收拢）+ **重心渐向左后挪**（卸载 FR）→ 完成回 `LOW`，**无翻膝**；全程缓慢、无磕碰、**前后腿动作对称、FR 不堵转、身体不往右前倾** |
| 兜底站起 | 再 `C` → 断电 → 上电 → `G` | G 强起（力矩大，仅记录现象对比） |
| 边界 | 非收纳状态发 `U` | 回 `NOT PARK`，不动作 |
| 大轮落地 | `C` 后目测 | 肚皮离地约 53mm；四轮应已着地（收纳全程轮子贴地滚动） |
| 大轮间隙 | `L`/`M` → `W` 抬腿 / `D:2:30` 压弯 | 108mm 大轮不蹭车身、不干涉腿（新轮径重点检查） |

> 关键观察：趴下速度是否均匀缓慢；断电后肚皮落差是否明显变小；U 站起全程是否顺滑。

---

## 结果记录总表

| # | 测试项 | 结果 ✓/✗ | 备注 |
|---|---|---|---|
| A | 上电自检 | | |
| B1~B8 | IMU 上报/诊断/符号/时序/断线 | | |
| C1 | G 狗高 | | |
| C2 | K 前顶高 | | |
| C3 | L 前顶低趴 | | |
| C4 | P 后顶高 | | |
| C5 | M 后顶低趴 | | |
| C6 | 切换矩阵 | | |
| C7 | 翻膝无磕碰 | | |
| D1 | T 纯 trot | | |
| D2 | A 单步 | | |
| D3 | W 越障 | | |
| D4 | E/E:0 转圈 | | |
| D5 | 边界记录 | | |
| E | 轮式 R/B/S/M 单控 + M 姿态不冲突 | | |
| F | ~~坡度~~已删除（自稳见 C10/C11） | | |
| G | X 前倾修正 | | |
| H | 异常边界 | | |
| I1 | 编码器转速上报（四通道核对） | | |
| I2 | V 前进 + 起步低头 + 到速回平 | | |
| I3 | V 渐停 + 刹车抬头 | | |
| I4 | V 后退 | | |
| I5 | V 转弯压弯（左右/混合） | | |
| I6 | 方向核对（前进/右转） | | |
| I7 | 交互边界（S/R/G/低趴） | | |
| I8 | 手感调优记录 | | |
| J | 方向按键（前进/后退/左前/右前 + 固定倾斜 + S 回平） | | |
| K | 收纳 C（断电落地/上电/G 一键站起） | | |

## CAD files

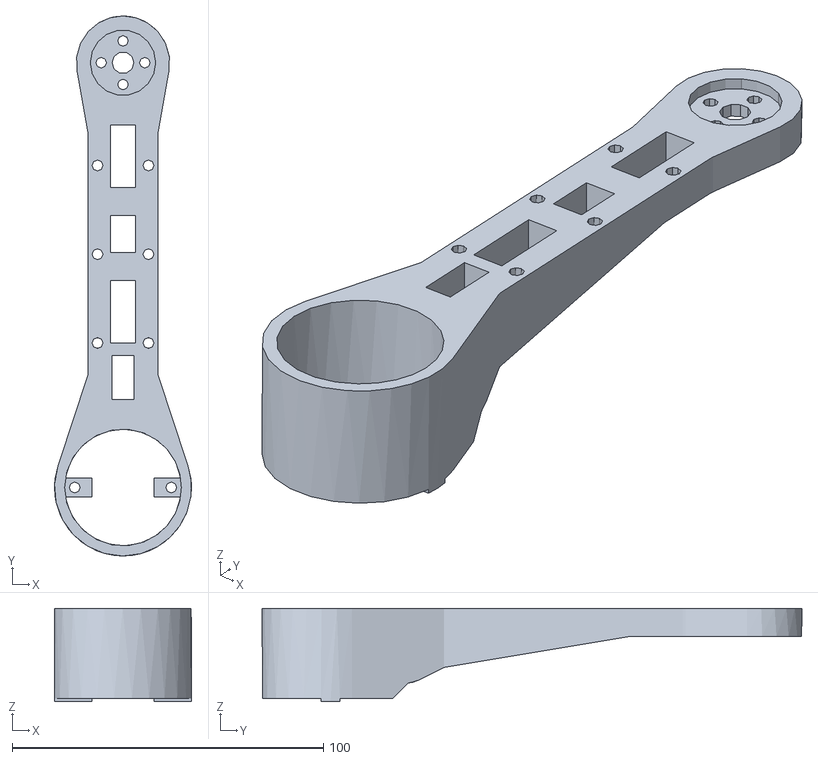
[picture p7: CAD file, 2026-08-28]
3D结构文件/下肢.stl
44.0 x 173.4 x 30.0

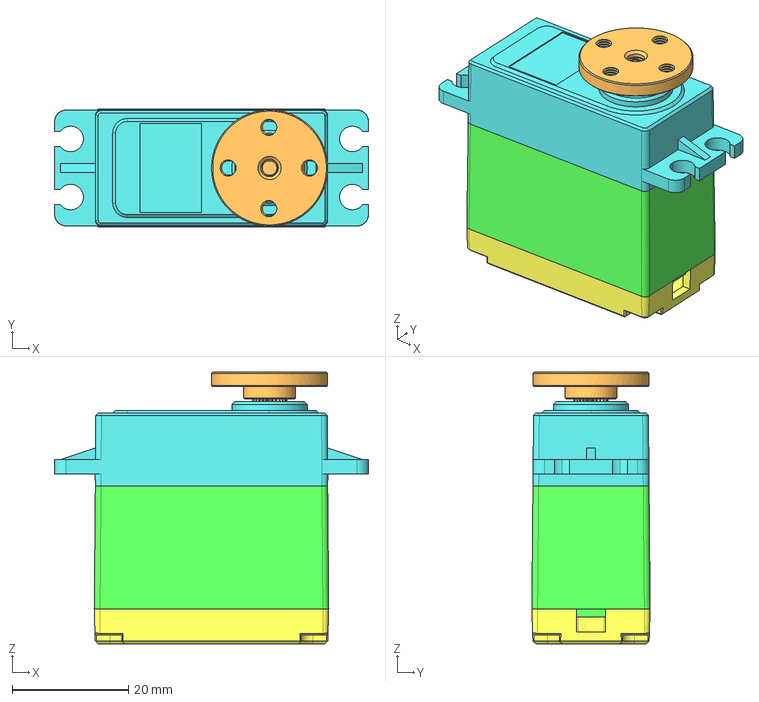
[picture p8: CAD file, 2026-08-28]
3D结构文件/标准舵机含舵盘3D.step
54.1 x 20.4 x 46.8 mm

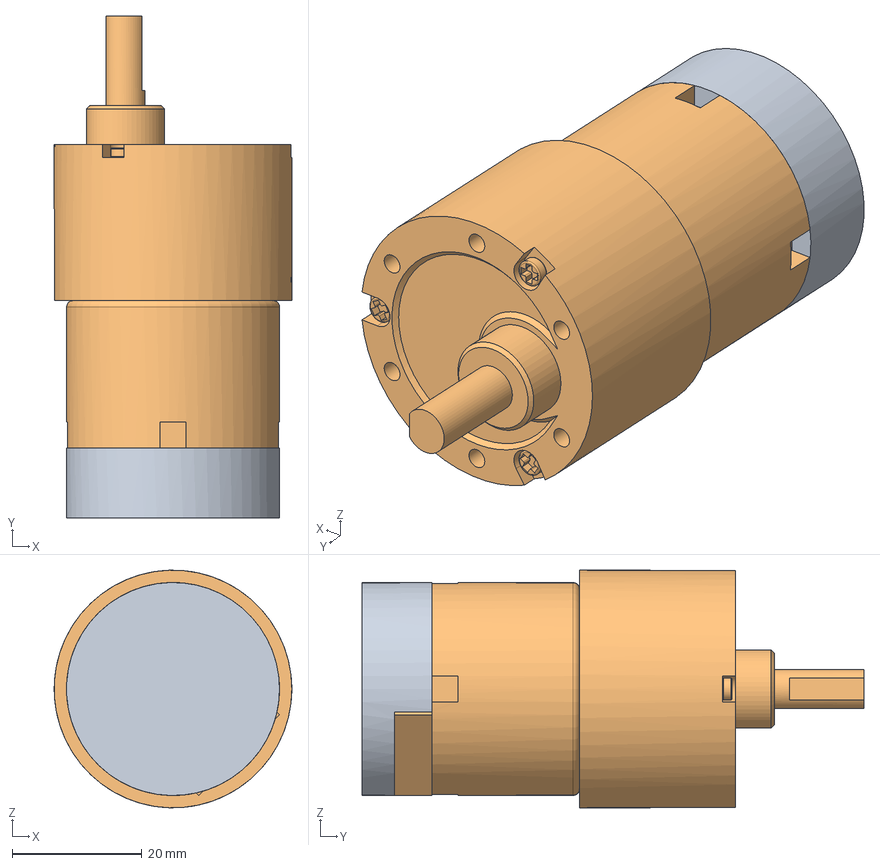
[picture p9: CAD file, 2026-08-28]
3D结构文件/直流电机_MG513P60-12V（GMR）.stp
36.6 x 77.3 x 36.6 mm

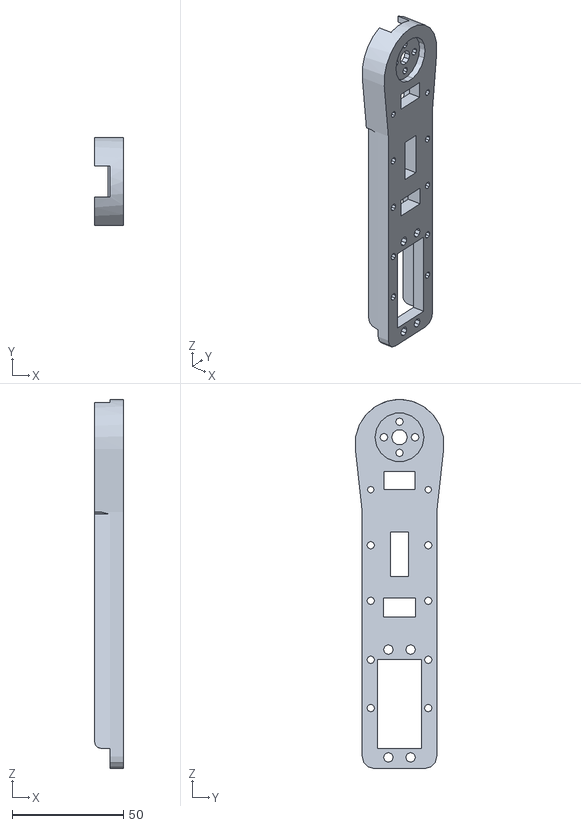
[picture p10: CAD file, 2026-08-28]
3D结构文件/上肢.stl
13.0 x 39.8 x 166.0

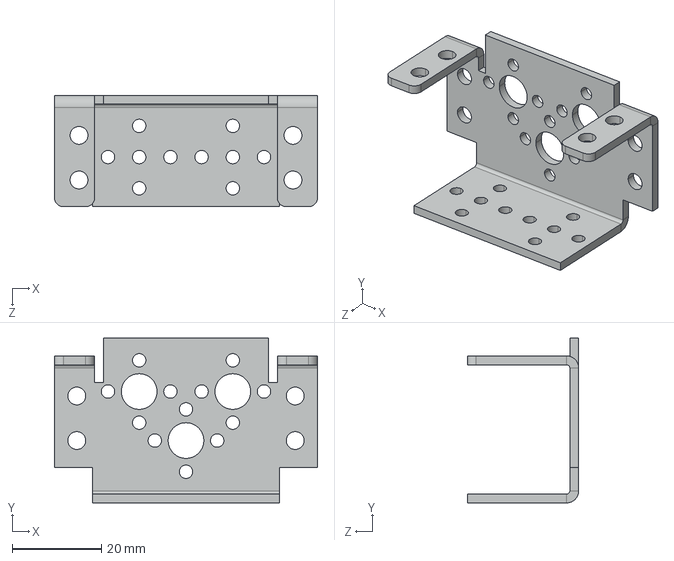
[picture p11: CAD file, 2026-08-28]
3D结构文件/舵机支架.STEP
59.0 x 37.0 x 25.0 mm

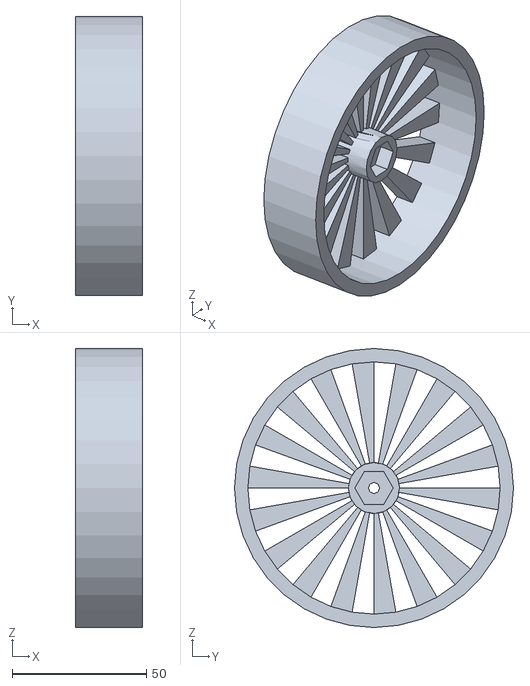
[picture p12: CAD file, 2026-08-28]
3D结构文件/轮子.stl
25.0 x 104.0 x 104.0

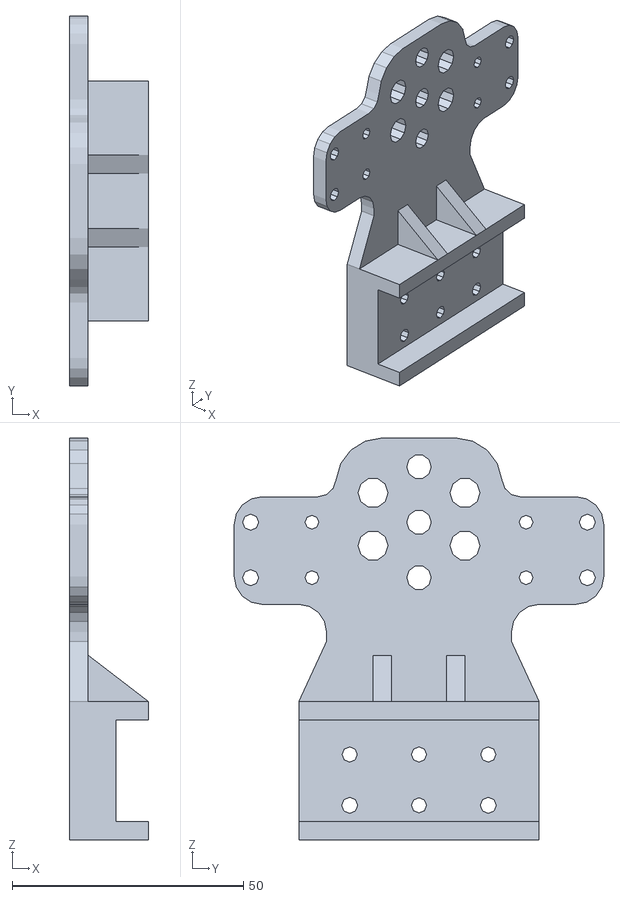
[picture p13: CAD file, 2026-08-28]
3D结构文件/lianjiejian.stl
17.0 x 80.0 x 87.0

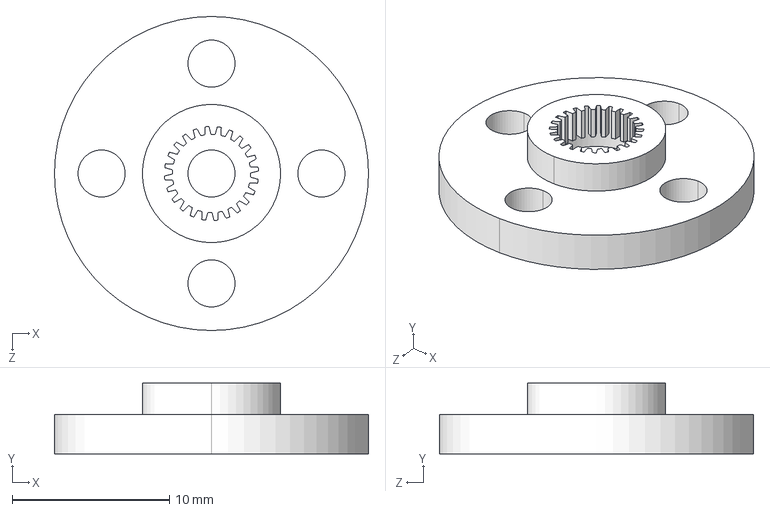
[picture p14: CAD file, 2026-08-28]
3D结构文件/金属主舵盘.STEP
20.0 x 4.50 x 20.0 mm

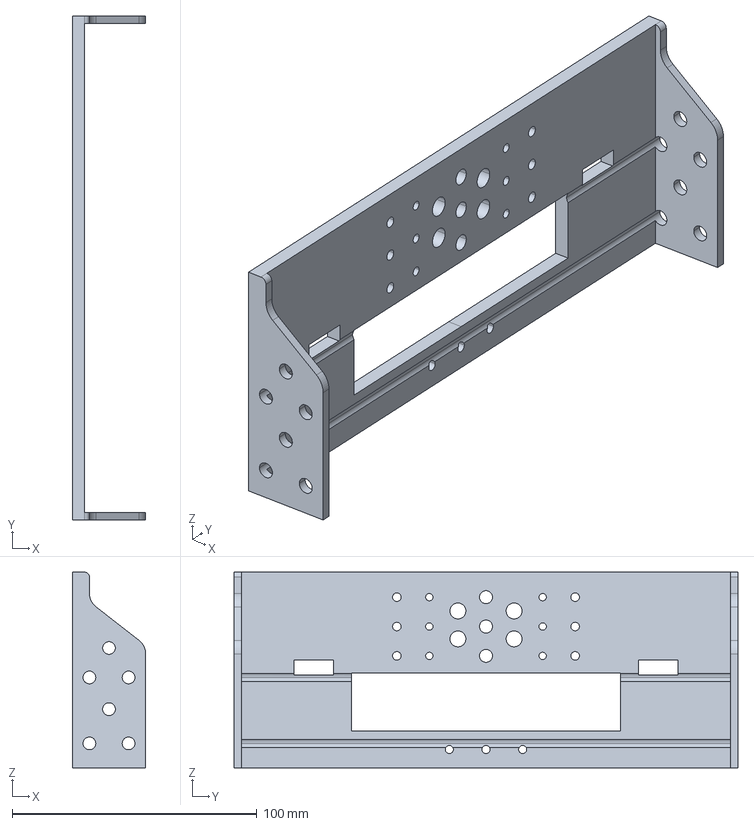
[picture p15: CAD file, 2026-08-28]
3D结构文件/前后件连接平台.stp
30.0 x 206.0 x 80.0 mm

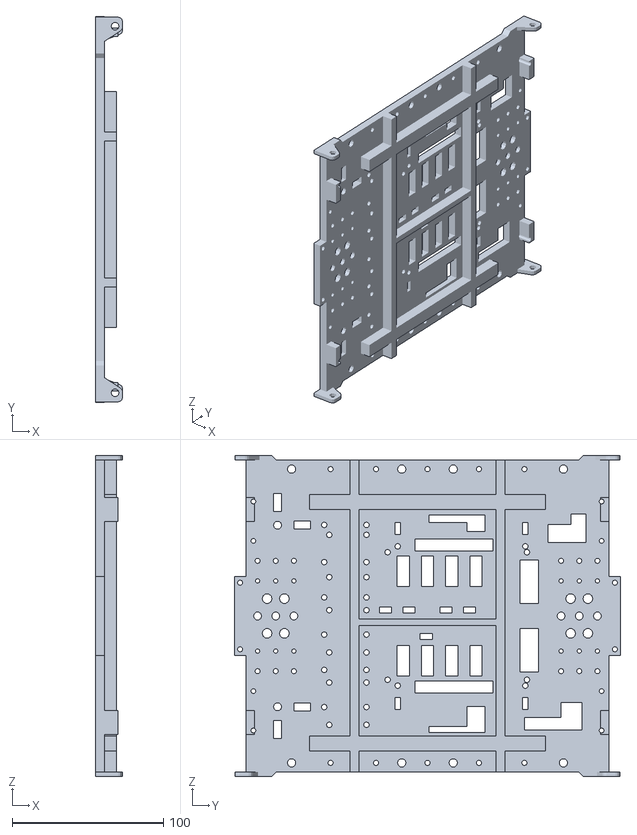
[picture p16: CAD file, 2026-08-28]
3D结构文件/中心底板.stl
18.0 x 255.0 x 212.0

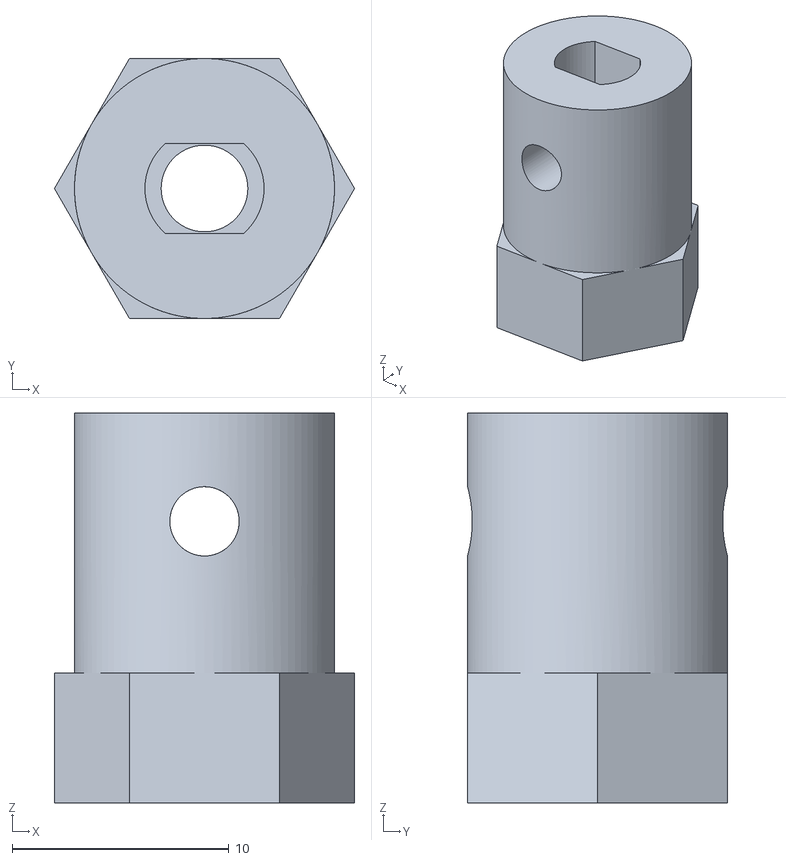
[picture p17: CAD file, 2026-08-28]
3D结构文件/六角联轴器.stl
13.9 x 12.0 x 18.0

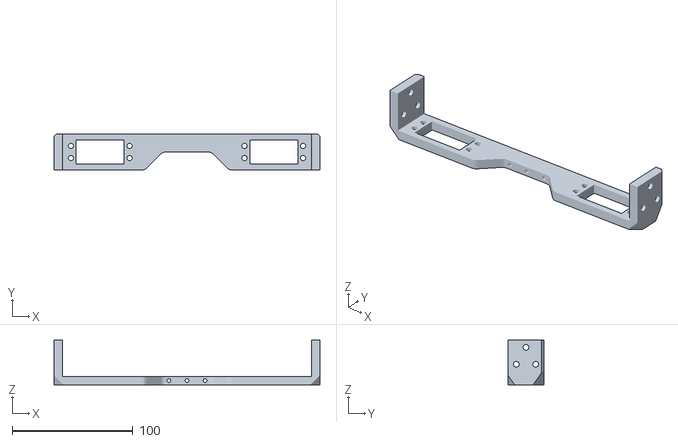
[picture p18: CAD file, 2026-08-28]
3D结构文件/前后舵机固定件.stl
220.0 x 30.0 x 37.0

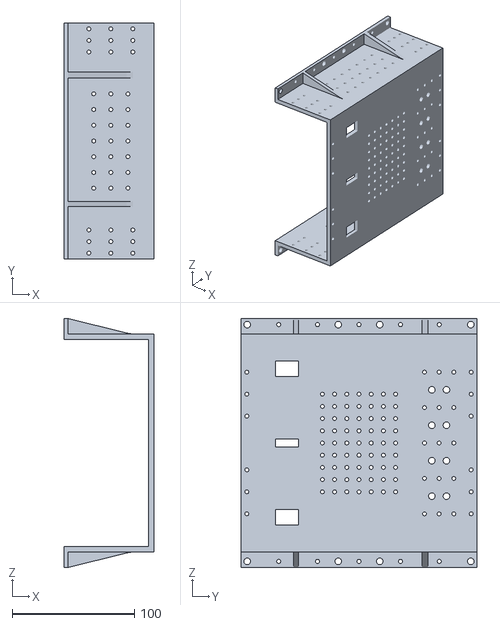
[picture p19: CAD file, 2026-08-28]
3D结构文件/gaizi.stl
74.0 x 193.2 x 204.0

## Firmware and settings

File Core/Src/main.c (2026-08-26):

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
/* Includes ------------------------------------------------------------------*/
#include "main.h"
#include "dcmi.h"
#include "dma.h"
#include "iwdg.h"
#include "spi.h"
#include "tim.h"
#include "usart.h"
#include "gpio.h"

/* USER CODE BEGIN Includes */
#include "motor_control.h"
#include "new_servo.h"
#include "leg_control.h"
#include "encoder.h"
#include "bluetooth_control.h"
#include "imu.h"
#include "leg_ik.h"
#include "walk_gait.h"
#include "attitude_control.h"
#include "drive_ctrl.h"
#include "gimbal.h"
#include <stdio.h>
#include <math.h>
/* USER CODE END Includes */

/* USER CODE BEGIN PTD */
/* 控制模式: 上电默认校准模式(不动), 蓝牙命令切换 */
typedef enum { MODE_CALIB = 0, MODE_STAND, MODE_TROT, MODE_STEP } ctrl_mode_t;

#define CROUCH_X_F   30.0f    /* 正常分支低趴: 前腿足端前伸 (膝轴离地86mm) */
#define CROUCH_X_FR 114.5f    /* 反折分支低趴: 前足+129.5, 大腿≈水平(q2=85)+小腿垂直(q3=-85) */
#define CROUCH_X_R  144.5f    /* 正常分支低趴后伸: 后足15-144.5=-129.5, 与前足对称 (L 视觉姿态) */
#define CROUCH_X_RR 135.0f    /* 反折分支低趴后伸 (支撑中心在身下, 前后对称) */

#define FLIP_H         240.0f /* 翻膝机动高度: 此高度下前膝全程≥110mm */
#define FLIP_SEG_MS    900u   /* 翻膝单段时长 (伸/收各900ms) */
#define FLIP_SETTLE_MS 800u   /* 到位后等待平滑收敛再翻膝 */

#define PARK_H          72.0f /* 收纳姿态站高: 贴地趴 (肚皮离地~32mm, 断电无砸落) */
#define PARK_X_F       282.0f /* 贴地趴前足前伸量 (15+282=297, 腿伸直) */
#define PARK_X_R       312.0f /* 贴地趴后足后伸量 (15-312=-297) */

#define RISE_CM_X       15.0f /* 站起阶段重心后移量: 足端前移=身体后坐, 卸载前腿 */
#define RISE_CM_Y       10.0f /* 站起阶段重心左移量: 卸载右腿(FR堵转), 载荷给强壮的RL */

#define SIT_Z_F        310.0f /* 坐姿前腿足端z: 腿竖直伸直 (q2≈q3≈0, 直腿点) */
#define SIT_Z_R        240.0f /* 坐姿后腿足端z: 反折深蹲 */
#define SIT_X_R         95.0f /* 坐姿后足后伸量 (15-95=-80, 膝后折72°) */

/* 前后腿膝分支: 0=正常(狗姿态) 1=反折(膝盖往前顶) */
static uint8_t  g_front_rev = 0;
static uint8_t  g_rear_rev  = 0;
static uint8_t  g_park      = 0;   /* 收纳姿态 (C 命令): 72mm 贴地趴 */
static uint8_t  g_sit       = 0;   /* 坐姿 (O 命令): 前腿竖直伸直 + 后腿反折深蹲 */
static uint8_t  g_rise      = 0;   /* 规划式站起 (U 命令): 1=阶段A收腿+顶升 */
static uint32_t g_rise_t0   = 0;
static float    g_rise_h0   = 0;   /* 站起阶段A起始高度 */
static uint8_t  g_booted    = 1;   /* 刚上电标志: U 站起在上电后可用 (假定在趴姿) */

/* 控制模式与行走时刻 (PTD 函数也要用, 声明放这里) */
static ctrl_mode_t g_mode    = MODE_CALIB;
static uint32_t    g_walk_t0 = 0; /* 行走起始时刻 (相位基准) */

/* 横移走状态: F 命令开启 (0=前后trot, 1=横向螃蟹步), g_lat_dir 为方向 */
static uint8_t  g_gait_lat = 0;
static int      g_lat_dir  = 1;

/* 自稳标定: Z 命令采样中标志 (完成时发 CAL:OK) */
static uint8_t  g_calib_pending = 0;

/* 站立自稳: L:1/L:0 开关, 10Hz 更新四腿z补偿 (仅H/K高站姿, Z标定后可用) */
static float    g_lv_dz[4] = {0, 0, 0, 0};
static uint32_t g_lv_last  = 0;
static uint8_t  g_lv_act   = 0;   /* 自稳激活状态 (10Hz块更新, 行走循环消费) */

/* W原地抬腿重心左移补偿 (mm): 机身右侧偏重 → 右倾+右转, 足端右移=身体左移
 * W:毫米 命令在线调 (默认15) */
static float    g_w_com = 15.0f;

/* 按键页速度档 (D 命令缺省速度, U:1/U:0 加减, 步进5, 范围10~50) */
static int8_t   g_btn_spd     = 30;
static uint8_t  g_btn_dir     = 0;    /* 最后按键方向 */
static uint8_t  g_btn_mode    = 0;    /* 最后按键模式 0=经典 1=无倾斜页 */
static uint8_t  g_btn_driving = 0;    /* 当前是否按键驾驶中 (V摇杆接管时清) */

/* 站姿宽度偏移 (Y:毫米 命令, ±40, 默认0): 每足足端向外偏移, 支撑面加宽
 * 崎岖地面抗侧倾测试用; 同时用于实测验证外展y通道方向 */
static float    g_stance_w = 0.0f;

/* 单腿抬腿 (N:腿:动作): 任意时刻只操作一条腿
 * 抬起 50mm + 前伸 80mm (实测确认), 放下后足端停在前伸位, 姿态命令收回 */
#define LEGLIFT_H      50.0f   /* 抬腿高度 mm */
#define LEGLIFT_FWD    80.0f   /* 前伸量 mm */
#define LEGLIFT_UP_MS  800u    /* 抬起耗时 */
#define LEGLIFT_DN_MS  1200u   /* 放下耗时 (慢慢放) */
#define LEGLIFT_SHIFT  15.0f   /* 支撑腿重心横移 (mm): 远离抬起腿, 重心移进支撑三角形 */
#define LEGLIFT_STAG_MS 0u     /* 双腿模式交错间隔 (2026-08-25 改同时抬: 0=同时) */
static uint8_t  g_lift_leg   = 0xFF; /* 当前抬起的腿 0~3, 0xFF=无 */
static uint8_t  g_lift_phase = 0;    /* 1=抬起中 2=悬空 3=放下中 (0=待命) */
static uint32_t g_lift_t0    = 0;
static float    g_lift_x0    = 0;    /* 抬起起始x (站立位+前伸记忆) */
static float    g_lift_z3    = 0;    /* 放下起始z (抬起中被打断时为当前z) */
static float    g_lift_x3    = 0;    /* 放下起始x */
static float    g_lift_dx    = 0;    /* 本次抬腿的前伸增量 (已达80上限的腿=0, 原地抬) */
static float    g_leg_fwd[4] = {0, 0, 0, 0}; /* 每腿落地后的前伸记忆 (mm), 姿态命令清零 */

/* 抬腿状态是否作用于该腿: 单腿(0~3)精确匹配; 双腿模式 4=前双(0/1) 5=后双(2/3) */
static uint8_t LegLiftActive(uint8_t leg)
{
    if (g_lift_leg == leg) return 1;
    if (g_lift_leg == 4u && leg <= 1u) return 1;
    if (g_lift_leg == 5u && leg >= 2u) return 1;
    return 0;
}

/* 单腿/双腿抬腿缓动系数 (0→1, cos 平滑; 双腿模式第二条腿错开0.3s) */
static float LegLiftEase(uint8_t leg)
{
    uint32_t ms = (g_lift_phase == 1) ? LEGLIFT_UP_MS : LEGLIFT_DN_MS;
    uint32_t t0 = g_lift_t0;
    if (g_lift_leg >= 4u &&
        ((g_lift_leg == 4u && leg == 1u) || (g_lift_leg == 5u && leg == 3u)))
        t0 += LEGLIFT_STAG_MS;
    float u = (float)(uwTick - t0) / (float)ms;
    if (u < 0.0f) u = 0.0f;
    if (u > 1.0f) u = 1.0f;
    return 0.5f - 0.5f * cosf(3.14159265f * u);
}

/* 单腿抬腿足端 x: 抬起中边抬边前伸, 其余相位保持前伸位 (仅单腿模式用) */
static float LegLiftX(void)
{
    float xf = g_lift_x0 + g_lift_dx;
    if (g_lift_phase == 1) return g_lift_x0 + (xf - g_lift_x0) * LegLiftEase(g_lift_leg);
    if (g_lift_phase == 3) return g_lift_x3 + (xf - g_lift_x3) * LegLiftEase(g_lift_leg);
    return xf;
}

/* 单腿抬腿复位 (姿态/行走命令): 状态机 + 前伸记忆全清, 四足滚回站立位 */
static void LegLiftReset(void)
{
    g_lift_leg = 0xFF;
    g_lift_phase = 0;
    for (int i = 0; i < 4; i++) g_leg_fwd[i] = 0.0f;
}

/* 单腿/双腿抬腿足端 z (下向距离): 抬/悬/放 状态机 (双腿直抬, 无前伸) */
static float LegLiftZ(uint8_t leg, float h)
{
    float zu = h - LEGLIFT_H;
    if (g_lift_phase == 1) return h  + (zu - h) * LegLiftEase(leg);
    if (g_lift_phase == 2) return zu;
    if (g_lift_phase == 3) return g_lift_z3 + (h - g_lift_z3) * LegLiftEase(leg);
    return h;
}

/* IMU 上报: I 命令开关, 10Hz 固定频率 */
static uint8_t  g_imu_stream = 0;
static uint32_t g_imu_last   = 0;
static uint8_t  g_imu_diag   = 0;  /* I 按下后主循环发一次诊断 */

/* 编码器转速上报: J 命令开关, 10Hz */
static uint8_t  g_enc_stream = 0;
static uint32_t g_enc_last   = 0;

/* 翻膝机动状态 (姿态切换专用: 指定腿组的足端伸到直腿点再收回, 中点翻转膝分支) */
static uint8_t  g_flip_on    = 0;   /* 翻膝进行中 */
static uint32_t g_flip_t0    = 0;   /* 翻膝起始时刻 */
static uint32_t g_flip_start = 0;   /* 翻膝定时启动 (0=无计划) */
static uint8_t  g_flip_mask  = 0;   /* 翻膝腿组: bit0=前腿 bit1=后腿 */
static float    g_flip_x0f   = 0;   /* 前腿起点/终点x */
static float    g_flip_x0r   = 0;   /* 后腿起点/终点x */
static float    g_flip_xm    = 0;   /* 直腿点x幅度 (两分支在此连续) */
static uint8_t  g_flip_revf  = 0;   /* 翻膝后前腿分支 */
static uint8_t  g_flip_revr  = 0;   /* 翻膝后后腿分支 */
static uint8_t  g_flip_post  = 0;   /* 翻膝完成后: 1=趴LOW 2=升HIGH 3=开W 4=开F 5=趴PARK 7=坐姿 8=降到指定高度 */
static float    g_flip_post_h = 0;   /* post=8 的目标站高 (H:高度命令) */

/* 站起阶段重心挪移系数: h<100 无几何空间(腿近伸直), 100~160 渐变, ≥160 全量 */
static float RiseCmK(void)
{
    float k = (g_walk_params.stand_h - 100.0f) / 60.0f;
    if (k < 0.0f) return 0.0f;
    if (k > 1.0f) return 1.0f;
    return k;
}

/* 站姿足端 x: 前移修正 + 低趴外伸 + 坡度修正 (站高越低, 前后腿越往外伸) */
static float StandFootX(uint8_t leg)
{
    if (g_park) {
        /* 贴地趴: 前腿反折前伸直 x+297 / 后腿正常后伸直 x-297 (膝高~67mm) */
        if (leg < 2)
            return g_walk_params.foot_x_shift + PARK_X_F;
        return g_walk_params.foot_x_shift - PARK_X_R;
    }
    if (g_rise == 1) {
        /* 站起阶段A: 先顶升后收腿 (低力矩路径)
         * 反折前腿/正常后腿在低站高时只能近伸直前伸/后伸 (大腿 q2=±90 限制):
         * 足端收拢量随站高上升逐步放开, 沿 大腿(q2) + 小腿(q3) 双边界内收。
         * 2026-08-21 修复: 原轨迹只限小腿, 低处要求 q2>90 → IK钳位 →
         * 前腿被指令压进地面 (FR 堵转)。 */
        float h = g_walk_params.stand_h;
        /* 大腿 q2=±90 边界: 低处足端必须保持外伸, h≥180 后放开 (前后腿对称)
         * +2mm 安全余量: 目标恰好压在边界上时 IK 数值会微超 ±90 被钳 */
        float xq2 = (h < 180.0f) ? (130.0f + sqrtf(32400.0f - h * h) + 2.0f) : 0.0f;
        float bf = sqrtf(53361.0f - h * h);   /* FL小腿边界 (q3=-85) */
        if (bf < 0.0f) bf = 0.0f;
        float xf = 15.0f + CROUCH_X_FR;       /* =129.5, 前顶低趴前足 (h≤191恒k=1) */
        if (bf > xf)  xf = bf;
        if (xq2 > xf) xf = xq2;
        float br = sqrtf(43594.0f - h * h);   /* RL小腿边界 (q3=+97) */
        if (br < 0.0f) br = 0.0f;
        float xr = CROUCH_X_R - 15.0f;        /* =129.5, 前顶低趴后足幅度 (终点对齐L) */
        if (br > xr)  xr = br;
        if (xq2 > xr) xr = xq2;
        /* 重心后移: 足端整体前移 = 身体后坐, 卸载前腿 (FR 堵转补偿) */
        float cmx = RISE_CM_X * RiseCmK();
        if (leg < 2)
            return g_walk_params.foot_x_shift + xf + cmx;
        return g_walk_params.foot_x_shift - xr + cmx;
    }
    if (g_sit) {
        /* 坐姿: 前腿竖直伸直(x=0, z=310) + 后腿反折深蹲(x=-80, z=240) */
        if (leg < 2)
            return g_walk_params.foot_x_shift - 15.0f;
        return g_walk_params.foot_x_shift - SIT_X_R;
    }
    float k = (STAND_H_HIGH - g_walk_params.stand_h) / (STAND_H_HIGH - STAND_H_LOW);
    if (k < 0.0f) k = 0.0f;
    if (k > 1.0f) k = 1.0f;
    if (leg < 2)
        return g_walk_params.foot_x_shift +
               (g_front_rev ? CROUCH_X_FR * k : CROUCH_X_F * k);
    return g_walk_params.foot_x_shift -
           (g_rear_rev ? CROUCH_X_RR * k : CROUCH_X_R * k);
}

/* 直腿点x: 足端在高度h下伸到腿完全伸直的位置 (两分支在此连续) */
static float FlipStraightX(float h)
{
    float dmax = (LEG_L1 + LEG_L2) * 0.9999f;
    float d2 = dmax * dmax - h * h;
    return (d2 > 0.0f) ? sqrtf(d2) : 0.0f;
}

/* 开始翻膝机动 (前腿往+伸, 后腿往-伸) */
static void FlipBegin(void)
{
    g_flip_x0f = StandFootX(0) + g_walk_params.foot_x_corr[0];
    g_flip_x0r = StandFootX(2) + g_walk_params.foot_x_corr[2];
    g_flip_xm  = FlipStraightX(g_walk_params.stand_h);
    g_flip_t0  = uwTick;
    g_flip_on  = 1;
    bluetooth_send("FLIP\r\n");
}

/* 启动 trot: 恢复行走参数 + 停电机 + 相位归零, 可选重心横移模式
 * wheel_pct: 轮助走占空比 (T 前进行走=10%, E 转圈=0); back: 1=倒着走(负步幅+轮反向) */
static void TrotStart(uint8_t shift_mode, uint8_t wheel_pct, uint8_t back, const char *reply)
{
    g_flip_on = 0; g_flip_start = 0;
    g_walk_params.step_len = back ? -60.0f : 60.0f;   /* 负步幅=倒走 (支撑相反向推) */
    g_walk_params.step_h   = 25.0f;
    DriveCtrl_Reset();           /* 接管电机前先复位摇杆驱动 */
    g_booted = 0;
    g_sit = 0;
    g_shift_mode = shift_mode;
    g_gait_lat = 0;              /* 前后 trot */
    g_walk_t0 = uwTick;          /* 相位从零开始 */
    g_mode = MODE_TROT;
    for (int i = 0; i < 4; i++) {
        if (wheel_pct > 0)
            Motor_Set((uint8_t)i, wheel_pct, back ? 0 : 1);
        else
            Motor_Stop((uint8_t)i);
    }
    bluetooth_send(reply);
}
/* USER CODE END PTD */

/* USER CODE BEGIN PD */
#define CTRL_PERIOD_MS  5u    /* 控制节拍 5ms = 200Hz */
/* USER CODE END PD */


/* USER CODE BEGIN PV */
uint8_t bt_rx_byte;           /* 蓝牙接收字节 */
uint8_t imu_rx_byte;          /* IMU 接收字节 */
static float       g_cmd_deg[12];   /* 当前舵机指令角 (平滑用) */
static uint32_t    g_ctrl_last = 0; /* 控制节拍计时 */
static float       g_step_t    = 0; /* 单步调试: 冻结的行走时刻 */
static int         g_step_cnt  = 0; /* 单步计数 0~3 -> PH:0/90/180/270 */
static uint8_t     g_rise_slow    = 0;             /* 站高上升标记: 低趴升站用慢速平滑 */
static float       g_stand_h_prev = STAND_H_HIGH; /* 上一目标站高 (判升/降方向) */
static ctrl_mode_t g_mode_prev    = MODE_CALIB;   /* 上一拍模式 (退出行走时停轮用) */
/* USER CODE END PV */

void SystemClock_Config(void);
static void MPU_Config(void);
/* USER CODE BEGIN 0 */

// 弱实现：无调试器时防止printf调用空指针引发HardFault；调试器连接时semihosting覆盖此实现
__attribute__((weak)) int __io_putchar(int ch)
{
  (void)ch;
  return ch;
}

/* USER CODE END 0 */

/**
  * @brief  The application entry point.
  * @retval int
  */
int main(void)
{

  /* MPU Configuration--------------------------------------------------------*/
  MPU_Config();

  /* Enable the CPU Cache */

  /* Enable I-Cache---------------------------------------------------------*/
  SCB_EnableICache();

  /* Enable D-Cache---------------------------------------------------------*/
  SCB_EnableDCache();

  /* MCU Configuration--------------------------------------------------------*/

  /* Reset of all peripherals, Initializes the Flash interface and the Systick. */
  HAL_Init();

  /* Configure the system clock */
  SystemClock_Config();

  /* Initialize all configured peripherals */
  MX_GPIO_Init();
  MX_DMA_Init();
  MX_SPI6_Init();
  MX_DCMI_Init();
  MX_TIM2_Init();
  MX_TIM3_Init();
  MX_TIM4_Init();
  MX_TIM12_Init();
  MX_TIM1_Init();
  MX_TIM16_Init();
  MX_TIM17_Init();
  MX_TIM5_Init();
  MX_USART3_UART_Init();
  MX_USART2_UART_Init();
  MX_UART4_Init();
  MX_TIM13_Init();
  MX_TIM14_Init();
  MX_IWDG1_Init();
  /* USER CODE BEGIN 2 */

  /* ====== 舵机校准：先强制拉低引脚，再开 PWM ====== */
  HAL_GPIO_WritePin(GPIOA, GPIO_PIN_0|GPIO_PIN_1|GPIO_PIN_2|GPIO_PIN_3|GPIO_PIN_7, GPIO_PIN_RESET);
  HAL_GPIO_WritePin(GPIOB, GPIO_PIN_0|GPIO_PIN_1|GPIO_PIN_14, GPIO_PIN_RESET);
  HAL_GPIO_WritePin(GPIOD, GPIO_PIN_12|GPIO_PIN_13|GPIO_PIN_14|GPIO_PIN_15, GPIO_PIN_RESET);
  NewServo_StartAll();

  Motor_Init();   /* 电机 PWM 启动, CCR=0 不转, STBY 拉高待命 */

  Gimbal_Init();  /* 云台舵机 (TIM8 CH3/CH4), 默认居中 135/135 */

  /* 外展 4 舵机错开 100ms 上电锁定站姿角, 防乱动 */
  for (int leg = 0; leg < 4; leg++) {
      Leg_SetJoint((uint8_t)leg, JOINT_ABD, STAND_POSE[leg][JOINT_ABD]);
      HAL_Delay(100);
  }

  /* 指令角初始化: 外展=锁定值, 大腿/小腿=IK站姿解 (首次G写入即站姿, 不跳变) */
  LegIK_SetFrontReversed(0);   /* 上电默认狗姿态 (前后腿正常膝分支) */
  LegIK_SetRearReversed(0);
  for (int leg = 0; leg < 4; leg++) {
      float d_leg = (leg == 0 || leg == 2) ? -LEG_HIP_D : LEG_HIP_D;
      uint16_t deg[3];
      LegIK_SolveServo((uint8_t)leg, StandFootX((uint8_t)leg), d_leg, g_walk_params.stand_h, deg);
      g_cmd_deg[leg]     = (float)STAND_POSE[leg][JOINT_ABD];
      g_cmd_deg[leg + 4] = (float)deg[1];   /* 大腿 */
      g_cmd_deg[leg + 8] = (float)deg[2];   /* 小腿 */
  }

  HAL_UART_Receive_IT(&huart2, &imu_rx_byte, 1);   /* IMU 数据流 (PD6, 115200bps) */
  HAL_UART_Receive_IT(&huart3, &bt_rx_byte, 1);
  Encoder_Init();   /* 编码器计数清零 */
  bluetooth_send("READY\r\n");   /* 上电自检: TX/DMA 通不通 */

  /* 环回自测: PD5(TX) 发 5 字节, 短接 PD5-PD6 后 raw 应 >=5 */
  {
      static const uint8_t loop_test[] = {0x55, 0x51, 0x00, 0x00, 0xA6};
      HAL_UART_Transmit(&huart2, (uint8_t *)loop_test, 5, 100);
  }
  /* USER CODE END 2 */

  /* Infinite loop */
  /* USER CODE BEGIN WHILE */
  while (1)
  {
    /* USER CODE END WHILE */

    /* USER CODE BEGIN 3 */

    HAL_IWDG_Refresh(&hiwdg1);   /* 喂狗: 主循环死掉/Error_Handler 超2秒 → 自动复位, 蓝牙失效免断电 */

    /* ====== 编码器转速上报: J 命令开启后 10Hz, 帧尾 520 ====== */
    if (g_enc_stream && (uint32_t)(uwTick - g_enc_last) >= 100u) {
        g_enc_last = uwTick;
        static char ebuf[40];
        snprintf(ebuf, sizeof(ebuf), "E,%d,%d,%d,%d,520\r\n",
                 (int)DriveCtrl_GetRPM(0), (int)DriveCtrl_GetRPM(1),
                 (int)DriveCtrl_GetRPM(2), (int)DriveCtrl_GetRPM(3));
        bluetooth_send(ebuf);
    }

    /* ====== IMU 姿态上报: I 命令开启后 10Hz, 帧尾 520 (参考 adc_10 风格) ====== */
    if (g_imu_stream && (uint32_t)(uwTick - g_imu_last) >= 100u) {
        g_imu_last = uwTick;
        const IMU_Angle *a = IMU_GetAngle();
        /* 定点×10 (0.1°分辨率), 全整数传输, 避免浮点打印 */
        int16_t rx = (int16_t)(a->roll  * 10.0f + (a->roll  >= 0 ? 0.5f : -0.5f));
        int16_t px = (int16_t)(a->pitch * 10.0f + (a->pitch >= 0 ? 0.5f : -0.5f));
        int16_t yx = (int16_t)(a->yaw   * 10.0f + (a->yaw   >= 0 ? 0.5f : -0.5f));
        static char ibuf[40];   /* static: DMA 发送期间缓冲区必须有效 */
        snprintf(ibuf, sizeof(ibuf), "R,%d,P,%d,Y,%d,520\r\n", (int)rx, (int)px, (int)yx);
        bluetooth_send(ibuf);
    }

    /* ====== USART2 接收链看门狗: 每1s检查, 断链自动重装 (双保险) ====== */
    {
        static uint32_t rx_wd_last = 0;
        if ((uint32_t)(uwTick - rx_wd_last) >= 1000u) {
            rx_wd_last = uwTick;
            if (huart2.RxState != HAL_UART_STATE_BUSY_RX) {
                huart2.RxState = HAL_UART_STATE_READY;
                HAL_UART_Receive_IT(&huart2, &imu_rx_byte, 1);
            }
        }
    }

    /* ====== IMU 诊断: 按 I 后报告 USART2 寄存器与收发计数 (主循环发, 避开ISR DMA死锁) ====== */
    if (g_imu_diag) {
        g_imu_diag = 0;
        static char dbg[128];
        snprintf(dbg, sizeof(dbg),
            "DBG2:CR1=%08lX ISR=%08lX MODER=%08lX AFR=%08lX gSt=%d RxSt=%d raw=%lu frames=%lu\r\n",
            (unsigned long)USART2->CR1,
            (unsigned long)USART2->ISR,
            (unsigned long)GPIOD->MODER,
            (unsigned long)GPIOD->AFR[0],
            (int)huart2.gState, (int)huart2.RxState,
            (unsigned long)IMU_GetRawCount(),
            (unsigned long)IMU_GetFrameCount());
        bluetooth_send(dbg);
    }

    /* ====== IMU 诊断: I 开启但 5s 无有效帧 → 报告收发计数 ====== */
    if (g_imu_stream && IMU_Timeout(5000)) {
        static uint32_t diag_last = 0;
        if ((uint32_t)(uwTick - diag_last) >= 2000u) {  /* 每2s一条, 不刷屏 */
            diag_last = uwTick;
            static char dbuf[64];
            snprintf(dbuf, sizeof(dbuf),
                     "IMU:NO DATA raw=%lu frames=%lu\r\n",
                     (unsigned long)IMU_GetRawCount(),
                     (unsigned long)IMU_GetFrameCount());
            bluetooth_send(dbuf);
        }
    }

    /* ====== 5ms 控制节拍: IK解算 + 指数平滑 + 批量输出 ====== */
    if ((uint32_t)(uwTick - g_ctrl_last) >= CTRL_PERIOD_MS) {
        g_ctrl_last = uwTick;

        /* 翻膝定时启动 (命令设的延迟到点后开始) */
        if (g_flip_start && (int32_t)(uwTick - g_flip_start) >= 0) {
            g_flip_start = 0;
            FlipBegin();
        }

        /* 单腿抬腿状态机: 相位推进 + 模式失配自动清除 */
        if (g_lift_leg != 0xFF) {
            if (!(g_mode == MODE_STAND && !g_park && !g_rise &&
                  !g_flip_on && !g_sit)) {
                LegLiftReset();         /* 行走/翻膝/收纳/站起/坐姿: 自动收回 */
            } else if (g_lift_phase == 1 &&
                       (uint32_t)(uwTick - g_lift_t0) >=
                       LEGLIFT_UP_MS + ((g_lift_leg >= 4u) ? LEGLIFT_STAG_MS : 0u)) {
                g_lift_phase = 2;       /* 抬起完成: 悬空 (双腿含交错) */
            } else if (g_lift_phase == 3 &&
                       (uint32_t)(uwTick - g_lift_t0) >=
                       LEGLIFT_DN_MS + ((g_lift_leg >= 4u) ? LEGLIFT_STAG_MS : 0u)) {
                /* 放下完成: 单腿前伸记忆生效; 释放状态机 (其它腿立即可抬) */
                if (g_lift_leg < 4u)
                    g_leg_fwd[g_lift_leg] += g_lift_dx;
                g_lift_leg = 0xFF;
                g_lift_phase = 0;
            }
        }

        /* 摇杆驱动: 占空比斜坡 + 电机差速 + 倾斜状态机 (每5ms) */
        DriveCtrl_Update();

        /* 退出行走模式→站立时停轮 (T 轮助走10% 随行走结束停止; 急停用 S) */
        if (g_mode == MODE_STAND && g_mode_prev == MODE_TROT) {
            for (int i = 0; i < 4; i++)
                Motor_Stop((uint8_t)i);
        }
        g_mode_prev = g_mode;

        /* 规划式站起: 单段顶升+收腿 → 前顶低趴 191 (3.5s 缓升)
         * 2026-08-21 改: 趴姿(前反折+后正常)与前顶低趴同膝分支,
         * 免翻膝、免回高站姿, 直接站到 L 视觉姿态 (之后 G/K 可再升) */
        if (g_rise == 1) {
            float t = (float)(uwTick - g_rise_t0) / 1000.0f;
            float h = g_rise_h0 + (STAND_H_L_FRONT - g_rise_h0) * (t / 3.5f);
            if (h > STAND_H_L_FRONT) h = STAND_H_L_FRONT;
            g_walk_params.stand_h = h;
            if (t >= 3.5f) {
                g_rise = 0;
                bluetooth_send("LOW\r\n");   /* 站起完成: 前顶低趴 191 */
            }
        }

        /* IMU 行为层: 姿态ID跟随当前配置, Z标定每拍采样, 自稳10Hz更新 */
        {
            const IMU_Angle *ia = IMU_GetAngle();
            float pitch = ia->pitch;
            AttCtrl_SetPose(g_front_rev, g_rear_rev,
                            g_walk_params.stand_h >= STAND_H_HIGH);
            AttCtrl_CalibTick(pitch, ia->roll);
            if (g_calib_pending && !AttCtrl_CalibBusy()) {
                g_calib_pending = 0;
                bluetooth_send("CAL:OK\r\n");  /* 标定完成: 自稳零偏已存 */
            }
            /* 站立自稳: 更新四腿z补偿
             * 激活: 站立静止 / V模式1无倾斜驱动 / W原地抬腿(防对角支撑翘板)
             * W 用 50ms 快拍 + 快速低通 (翘板修正要快); 其余 100ms */
            {
                /* 注意: 空闲态 g_lift_leg=0xFF, 只排除双腿模式(4/5)
                 * W原地抬腿无条件自稳 (标定门控在LevelUpdate内), 不受轮盘标志影响 */
                uint8_t lv_stand = (g_mode == MODE_STAND) && !g_park && !g_rise &&
                                   !g_flip_on && !g_sit &&
                                   !(g_lift_leg == 4u || g_lift_leg == 5u) &&
                                   (AttCtrl_LevelEnabled() || DriveCtrl_LevelAuto());
                uint8_t lv_w = (g_mode == MODE_TROT) && !g_gait_lat &&
                               g_walk_params.step_len == 0.0f;
                g_lv_act = lv_stand || lv_w;
                if ((uint32_t)(uwTick - g_lv_last) >= (lv_w ? 50u : 100u)) {
                    g_lv_last = uwTick;
                    AttCtrl_LevelUpdate(pitch, ia->roll, g_walk_params.stand_h,
                                        g_lv_act, lv_w, g_lv_dz);
                }
            }
        }

        if (g_mode == MODE_STAND || g_mode == MODE_TROT || g_mode == MODE_STEP) {
            /* 目标站高变化: 上升(低趴站起, 大轮负载重)标记慢速, 下降保持原手感 */
            if (g_walk_params.stand_h != g_stand_h_prev) {
                g_rise_slow = (g_walk_params.stand_h > g_stand_h_prev) ? 1 : 0;
                g_stand_h_prev = g_walk_params.stand_h;
            }
            /* 平滑速率: 收纳/站起最慢; 低趴升站慢速(0.04≈1.5s); 翻膝用原速(时序对齐) */
            float rate = (g_park || g_rise) ? 0.008f
                       : ((g_mode == MODE_STAND)
                          ? ((g_rise_slow && !g_flip_on) ? 0.04f : 0.12f)
                          : ((g_walk_params.step_len == 0.0f) ? 0.40f : 0.20f));  /* W原地抬腿跟随更快 */
            uint16_t angles[12];

            for (uint8_t leg = 0; leg < 4; leg++) {
                float d_leg = (leg == 0 || leg == 2) ? -LEG_HIP_D : LEG_HIP_D;
                uint16_t deg[3];
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

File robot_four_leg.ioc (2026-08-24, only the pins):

Mcu.UserName=STM32H743ZITx
PA0.Signal=S_TIM2_CH1_ETR
PA1.Signal=S_TIM2_CH2
PA10.GPIO_Label=STBY
PA10.Signal=GPIO_Output
PA2.Signal=S_TIM2_CH3
PA3.Signal=S_TIM2_CH4
PA4.Signal=DCMI_HSYNC
PA6.Signal=DCMI_PIXCLK
PA7.Signal=S_TIM3_CH2
PA8.Signal=S_TIM1_CH1
PA9.Signal=S_TIM1_CH2
PB0.Signal=S_TIM3_CH3
PB1.Signal=S_TIM3_CH4
PB10.Signal=USART3_TX
PB11.Signal=USART3_RX
PB12.GPIO_Label=DIN2
PB12.Signal=GPIO_Output
PB14.Signal=S_TIM12_CH1
PB5.GPIO_Label=CIN1
PB5.Signal=GPIO_Output
PB6.GPIO_Label=CIN2
PB6.Signal=GPIO_Output
PB7.GPIO_Label=DIN1
PB7.Signal=GPIO_Output
PB8.Signal=S_TIM16_CH1
PB9.Signal=S_TIM17_CH1
PC10.Signal=UART4_TX
PC11.Signal=UART4_RX
PC6.Signal=DCMI_D0
PC7.Signal=DCMI_D1
PD12.Signal=S_TIM4_CH1
PD13.Signal=S_TIM4_CH2
PD14.Signal=S_TIM4_CH3
PD15.Signal=S_TIM4_CH4
PD3.Signal=DCMI_D5
PD5.Signal=USART2_TX
PD6.Signal=USART2_RX
PE0.GPIO_Label=AIN1
PE0.Signal=GPIO_Output
PE1.GPIO_Label=AIN2
PE1.Signal=GPIO_Output
PE10.GPIO_Label=ENC2_B
PE10.Signal=GPIO_Input
PE11.GPIO_Label=ENC3_A
PE11.Signal=GPXTI11
PE12.GPIO_Label=ENC3_B
PE12.Signal=GPIO_Input
PE13.GPIO_Label=ENC4_A
PE13.Signal=GPXTI13
PE14.GPIO_Label=ENC4_B
PE14.Signal=GPIO_Input
PE2.GPIO_Label=BIN1
PE2.Signal=GPIO_Output
PE3.GPIO_Label=BIN2
PE3.Signal=GPIO_Output
PE4.Signal=DCMI_D4
PE5.Signal=DCMI_D6
PE6.Signal=DCMI_D7
PE7.GPIO_Label=ENC1_A
PE7.Signal=GPXTI7
PE8.GPIO_Label=ENC1_B
PE8.Signal=GPIO_Input
PE9.GPIO_Label=ENC2_A
PE9.Signal=GPXTI9
PF13.GPIO_Label=PWDN
PF13.Signal=GPIO_Output
PF14.GPIO_Label=SCCB_SCL
PF14.Signal=GPIO_Output
PF15.GPIO_Label=SCCB_SDA
PF15.Signal=GPIO_Output
PF8.Signal=S_TIM13_CH1
PF9.Signal=S_TIM14_CH1
PG10.Signal=DCMI_D2
PG11.Signal=DCMI_D3
PG12.GPIO_Label=LCD_BL
PG12.Signal=GPIO_Output
PG13.Signal=SPI6_SCK
PG14.Signal=SPI6_MOSI
PG15.GPIO_Label=LCD_DC
PG15.Signal=GPIO_Output
PG8.Signal=SPI6_NSS
PG9.Signal=DCMI_VSYNC

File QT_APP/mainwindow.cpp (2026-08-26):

#include "mainwindow.h"
#include <QVBoxLayout>
#include <QHBoxLayout>
#include <QGridLayout>
#include <QSlider>
#include <QGroupBox>
#include <QFrame>
#include <QScrollArea>
#include <QDateTime>
#include <QBluetoothDeviceInfo>
#include <QTimer>
#include <QSettings>
#include <QCoreApplication>
#include <QJniObject>
#if defined(Q_OS_ANDROID)
#include <QtCore/qnativeinterface.h>
#endif

// 石墨极简风 (v6.10): 近黑灰底 + 琥珀强调 + 多色语义保留
const QString MainWindow::C_BG     = QStringLiteral("#141518");
const QString MainWindow::C_CARD   = QStringLiteral("#1e2024");
const QString MainWindow::C_ACCENT = QStringLiteral("#2a2d33");
const QString MainWindow::C_BLUE   = QStringLiteral("#3b82f6");
const QString MainWindow::C_GREEN  = QStringLiteral("#22c55e");
const QString MainWindow::C_ORANGE = QStringLiteral("#f59e0b");
const QString MainWindow::C_RED    = QStringLiteral("#ef4444");
const QString MainWindow::C_TXT    = QStringLiteral("#e5e7eb");
const QString MainWindow::C_DIM    = QStringLiteral("#6b7280");

static bool isTarget(const QString &n)
{
    QString u = n.toUpper();
    return u.contains(QStringLiteral("HC-05")) || u.contains(QStringLiteral("HC-06"))
        || u.contains(QStringLiteral("ROBOT"));
}

static void sGrp(QGroupBox *g, const QString &t)
{
    g->setTitle(t);
    g->setStyleSheet(QString(
        "QGroupBox{font-size:11px;font-weight:bold;color:%1;"
        "border:1px solid %2;border-radius:10px;margin-top:10px;padding-top:14px;}"
        "QGroupBox::title{subcontrol-origin:margin;left:10px;padding:0 4px;color:%3;}")
        .arg(MainWindow::C_TXT, MainWindow::C_ACCENT, MainWindow::C_DIM));
}
static QString mkStyleB(const QString &bg)
{
    return QString(
        "QPushButton{border:none;border-radius:10px;padding:4px 10px;"
        "font-size:11px;font-weight:bold;color:#fff;background:%1;}"
        "QPushButton:disabled{background:#2a2c31;color:#5a5f68;}").arg(bg);
}
static QPushButton *mkB(const QString &t, const QString &bg)
{
    auto *b = new QPushButton(t); b->setMinimumHeight(30);
    b->setStyleSheet(mkStyleB(bg));
    return b;
}

MainWindow::MainWindow(QWidget *parent) : QMainWindow(parent) { setupUi();
    m_lastAddr = QSettings().value(QStringLiteral("bt/lastAddr")).toString();  // v6.10 一键重连
    m_btnReconnect->setVisible(!m_lastAddr.isEmpty());
    m_bt = new BluetoothClient(this);
    connect(m_bt, &BluetoothClient::stateChanged, this, &MainWindow::onBtStateChanged);
    connect(m_bt, &BluetoothClient::deviceDiscovered, this, &MainWindow::onDeviceDiscovered);
    connect(m_bt, &BluetoothClient::servoResponseReceived, this, &MainWindow::onServoResponse);
    connect(m_bt, &BluetoothClient::pidMessageReceived, this, &MainWindow::onPidMessage);
    connect(m_bt, &BluetoothClient::motorResponseReceived, this, &MainWindow::onMotorResponse);
    connect(m_bt, &BluetoothClient::telemetryReceived, this, &MainWindow::onTelemetry);
    connect(m_bt, &BluetoothClient::rawLineReceived, this, [this](const QString &l) {
        if (l.startsWith(QStringLiteral("READY"))) {
            appendLog(QStringLiteral("🤝 READY — 固件就绪"), C_GREEN);
            setPoseState(QStringLiteral("上电初始"));
            setActState(QStringLiteral("校准模式"), C_ORANGE);
            // v6.14 固件上电/看门狗复位: 云台自动回正 90/120, 同步 APP 轮盘显示
            m_gimbalPanDeg = 90; m_gimbalTiltDeg = 120;
            if (m_gimbalDial) m_gimbalDial->setValue(90, 120);
            if (m_gimbalStateLabel) {
                m_gimbalStateLabel->setText(QStringLiteral("✅ 水平 90° / 俯仰 120° (正对前方)"));
                m_gimbalStateLabel->setStyleSheet(QString(
                    "font-size:13px;font-weight:bold;color:%1;background:%2;border-radius:10px;padding:8px;")
                    .arg(C_TXT, C_CARD));
            }
        }
        else if (l.startsWith(QStringLiteral("UNK:")))
            appendLog(QStringLiteral("⚠ 固件不认识: %1").arg(l.mid(4)), C_ORANGE);
        else if (l.startsWith(QStringLiteral("CALIB"))) {
            // v6.12 Z = 自稳标定 (放平静止2s, 每姿态单独存; 重复按重标)
            appendLog(QStringLiteral("⚖ 自稳标定中 (放平静止2s)..."), C_ORANGE);
            m_slopeState->setText(QStringLiteral("状态: 标定中..."));
            m_slopeState->setStyleSheet(QString("font-size:11px;font-weight:bold;color:%1;background:transparent;").arg(C_ORANGE));
            setActState(QStringLiteral("自稳标定中"), C_ORANGE);
        }
        else if (l.startsWith(QStringLiteral("CAL:OK"))) {
            // v6.12 标定完成: 零偏已存, 可开自稳 L:1 (V 模式1 自动跟随)
            appendLog(QStringLiteral("⚖ 自稳标定完成 — 零偏已存, 可开自稳 L:1"), C_GREEN);
            m_slopeState->setText(QStringLiteral("状态: 已标定"));
            m_slopeState->setStyleSheet(QString("font-size:11px;font-weight:bold;color:%1;background:transparent;").arg(C_GREEN));
            setActState(QStringLiteral("站立"), C_GREEN);
        }
        else if (l.startsWith(QStringLiteral("LV:ON"))) {
            // v6.14 站立自稳开启 (v6.19 按键页自稳按钮同步)
            appendLog(QStringLiteral("🦿 站立自稳已开启 (H/K 高站姿 z 差动补偿)"), C_GREEN);
            m_lvOn = true;
            if (m_lvState) {
                m_lvState->setText(QStringLiteral("状态: 已开启"));
                m_lvState->setStyleSheet(QString("font-size:11px;font-weight:bold;color:%1;background:transparent;").arg(C_GREEN));
            }
            if (m_btnLv) m_btnLv->setText(QStringLiteral("L:0 关"));
            if (m_btnLv2) m_btnLv2->setText(QStringLiteral("自稳开 (L:0 关)"));
        }
        else if (l.startsWith(QStringLiteral("LV:OFF"))) {
            appendLog(QStringLiteral("🦿 站立自稳已关闭"), C_DIM);
            m_lvOn = false;
            if (m_lvState) {
                m_lvState->setText(QStringLiteral("状态: 关闭"));
                m_lvState->setStyleSheet(QString("font-size:11px;font-weight:bold;color:%1;background:transparent;").arg(C_DIM));
            }
            if (m_btnLv) m_btnLv->setText(QStringLiteral("L:1 开"));
            if (m_btnLv2) m_btnLv2->setText(QStringLiteral("自稳关 (L:1 开)"));
        }
        else if (l.startsWith(QStringLiteral("LV:NOCAL"))) {
            appendLog(QStringLiteral("⚠ 自稳未标定 — 先发 Z 标定当前姿态 (静止2s)"), C_ORANGE);
            m_lvOn = false;
            if (m_lvState) {
                m_lvState->setText(QStringLiteral("状态: 未标定"));
                m_lvState->setStyleSheet(QString("font-size:11px;font-weight:bold;color:%1;background:transparent;").arg(C_ORANGE));
            }
            if (m_btnLv) m_btnLv->setText(QStringLiteral("L:1 开"));
            if (m_btnLv2) m_btnLv2->setText(QStringLiteral("自稳关 (L:1 开)"));
        }
        else if (l.startsWith(QStringLiteral("LG:"))) {
            // v6.19 单腿抬腿回显: LG:腿,1 抬 / LG:腿,0 放 / LG:BUSY 互斥忙 / LG:NO 非站立
            static const char *legNames[4] = {"左前", "右前", "左后", "右后"};
            if (m_legStateLabel) {
                if (l.startsWith(QStringLiteral("LG:BUSY"))) {
                    m_legStateLabel->setText(QStringLiteral("⏳ 忙 — 先把当前腿放下再操作其它腿"));
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

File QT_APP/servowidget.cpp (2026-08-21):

#include "servowidget.h"
#include <QVBoxLayout>
#include <QHBoxLayout>
#include <QGridLayout>
#include <QFrame>
#include <QFileDialog>
#include <QMessageBox>
#include <QFile>
#include <QTextStream>

static const QString C_BG    = QStringLiteral("#141518");
static const QString C_CARD  = QStringLiteral("#1e2024");
static const QString C_TXT   = QStringLiteral("#e5e7eb");
static const QString C_DIM   = QStringLiteral("#6b7280");
static const QString C_BLUE  = QStringLiteral("#3b82f6");
static const QString C_GREEN = QStringLiteral("#22c55e");
static const QString C_RED   = QStringLiteral("#ef4444");
static const QString C_ORANGE= QStringLiteral("#f59e0b");
static const QString C_ACC   = QStringLiteral("#2a2d33");

static QPushButton *mkB(const QString &t, const QString &bg, int h = 30, int fw = 0)
{
    auto *b = new QPushButton(t);
    b->setMinimumHeight(h);
    if (fw) b->setFixedWidth(fw);
    b->setStyleSheet(QString(
        "QPushButton{border:none;border-radius:12px;padding:4px 8px;"
        "font-size:11px;font-weight:bold;color:#fff;background:%1;}"
        "QPushButton:disabled{background:#2a2a30;color:#555;}").arg(bg));
    return b;
}

ServoWidget::ServoWidget(QWidget *parent) : QWidget(parent)
{
    for (int i = 0; i < 12; i++) m_savedAngles[i] = -1;
    setupUi();
}

void ServoWidget::setupUi()
{
    setStyleSheet(QString("background:%1;border-radius:12px;").arg(C_CARD));
    auto *root = new QVBoxLayout(this);
    root->setContentsMargins(12, 8, 12, 8); root->setSpacing(6);

    auto *title = new QLabel(QStringLiteral("舵机校准 — 多舵机 + 两步确认"));
    title->setStyleSheet(QString("font-size:11px;font-weight:bold;color:%1;background:transparent;").arg(C_BLUE));
    root->addWidget(title);
    auto *sep = new QFrame; sep->setFrameShape(QFrame::HLine);
    sep->setStyleSheet(QStringLiteral("color:#2a2d33;")); sep->setFixedHeight(1);
    root->addWidget(sep);

    // ── 主体: 左(舵机选择+槽位) | 右(角度控制+确认) ──
    auto *body = new QHBoxLayout; body->setSpacing(10);
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

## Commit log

2026-08-13 feat: 初始化四足机器人工程（STM32H743 固件 + QT 蓝牙控制端）
2026-08-13 docs: 新增协作开发指南（Fork + PR 工作流）
2026-08-13 docs: 新增项目 README
2026-08-15 feat: 步态重构为 3D IK（leg_ik 三关节逆解 + walk_gait 足端轨迹，含实测标定数据）
2026-08-16 feat: 高/低站姿切换与前倾修正（H/L/X 命令）+ 舵机重标定，新增行程余量校验工具
    [main.c, mainwindow.cpp, motorwidget.cpp]
2026-08-17 feat: 新增越障模式 W（四轮前进+高站姿原地抬腿）与后退命令 B
2026-08-17 feat: 翻膝机动（前腿膝分支翻转 + 低趴足端外伸策略）
2026-08-18 feat: IMU 坡度自适应控制层（轮式爬坡姿态保持），新增姿态控制方案与排错文档
2026-08-19 feat: 摇杆差速驱动 V 命令（含起停/转弯倾斜平衡）+ QT 虚拟摇杆控件，新增功能总览文档
2026-08-21 feat: U 站起机动（姿态路径/可行性/余量校验工具 + 分垄接线指南）
2026-08-22 refactor: 用户模块 Core→Hardware 迁移，新增云台控制（gimbal）+ QT 视觉检测（颜色/运动），移除 LCD/摄像头驱动
2026-08-24 feat: 独立看门狗 IWDG + 站立自稳（L/Z 标定命令），QT 新增云台旋钮与光线检测
2026-08-24 feat: W 抬腿重心补偿（W:毫米 在线调）+ 自稳扩展至 W 模式，QT 新增启动画面
2026-08-26 feat: 单腿抬腿（N 命令，cos 平滑+重心横移）+ 按键速度档（U）+ 站姿宽度偏移（Y）
2026-08-27 docs: iCAN 开发日志与需求文档（6 阶段定稿版）
2026-08-27 docs: 清理内部过程文档（CubeMX 配置、开工简报、协作指南、过时模块文档）
2026-08-27 docs: 修正附件设计稿描述（3D 打印模型）
2026-08-27 docs: IMU 方案更新为最终实现版；仓库移除开发日志.md（仅保留正式版）
2026-08-27 docs: 轮式速度参数修正（300rpm 最高转速 → 1.7 m/s）
2026-08-27 docs: 需求文档轮式速度同步修正
2026-08-28 docs: 删除使用说明章节，后续章节序号前移（一~九）
2026-08-28 cleanup: README 更新至最终硬件配置；移除无关测试代码与临时文件；去个人化
2026-08-28 docs: 合并团队修订（V6.0/野外复杂环境/3kg/团队分工细化），修正成本与问题表序号
2026-08-28 docs: 恢复附件超链接，修正参考文献格式
2026-08-28 docs: 参考文献按 GB/T 7714 格式规范（作者姓前大写、补出版地与引用日期）
2026-08-28 docs: 修复附件超链接段落字体字号（与正文统一）
2026-08-28 docs: 参考文献编号格式调整
2026-08-28 docs: 移除易出格式问题的英文期刊文献，参考文献精简为 4 条
2026-08-28 repo: 上传 3D 打印模型文件；提交材料移出仓库（见材料包）；README 与附件说明更新
    [gaizi.stl, lianjiejian.stl, 上肢.stl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]

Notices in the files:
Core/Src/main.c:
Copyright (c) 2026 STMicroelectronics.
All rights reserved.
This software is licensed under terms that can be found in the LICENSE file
